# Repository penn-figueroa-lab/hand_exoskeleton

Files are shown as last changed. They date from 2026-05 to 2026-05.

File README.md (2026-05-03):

# Hand Exoskeleton — Figueroa Robotics Lab, University of Pennsylvania

<p align="center">
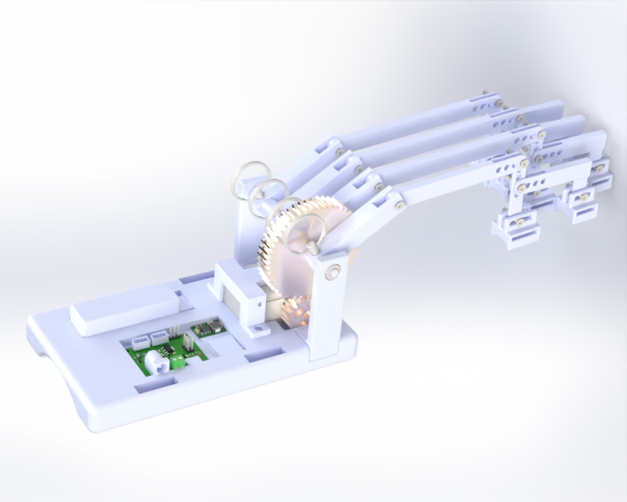
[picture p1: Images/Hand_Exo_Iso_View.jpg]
Hand Exoskeleton Rendered CAD
  
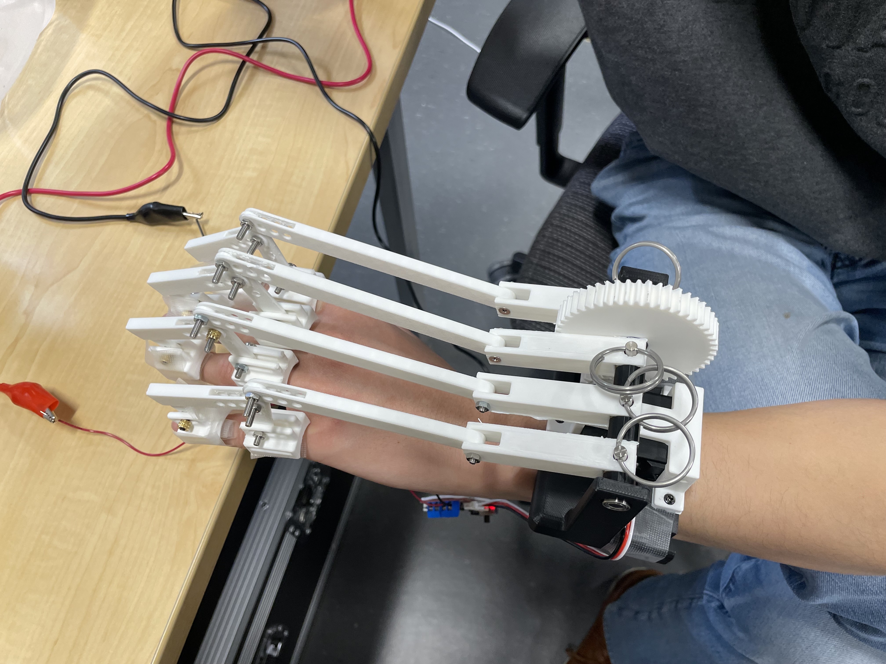
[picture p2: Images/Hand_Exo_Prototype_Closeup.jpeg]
Hand Exoskeleton Physical Prototype
  
</p>
<p align="center">
  <em>Left: SolidWorks render of the left-hand exoskeleton. Right: Physical prototype worn on a user's hand, showing the 4-finger linkage system, spur gear transmission, and wrist-mounted electronics housing.</em>
</p>

> **Status: Active Development** — Current version supports 4-finger actuation (index, middle, ring, pinky). Thumb integration is ongoing.

---

## Overview

This repository contains all design files, electronics documentation, and assembly instructions for the **Penn GRASP Lab Hand Exoskeleton** — a compact, single-motor, bidirectional hand exoskeleton designed to assist patients who retain partial voluntary hand control (e.g., post-stroke or spinal cord injury patients).

The device targets grip assistance by actuating all four fingers simultaneously through a single Waveshare ST3215 servo motor, a gear transmission, and a parallel four-bar linkage system per finger. All structural components are 3D printed in PLA on a single print bed, keeping cost and fabrication time low while maintaining sufficient mechanical strength for the target torque requirements.

This design draws inspiration from and extends the work of [Esposito et al. (2022) — *Machines*, MDPI](https://www.mdpi.com/2075-1702/10/1/57), adapting it for a more compact, wrist-mounted form factor with a spur gear transmission replacing a Bowden cable mechanism.

---

## Repository Structure

```
hand_exoskeleton/
├── Images/                        # Photos and renders used in this README
├── CAD/
│   ├── Hand Exoskeleton - Left/   # SolidWorks assembly and part files (left hand)
│   └── STL Files/                 # Exported STL files for all printed parts
├── Print files/
│   ├── BambuStudio/               # `Hand Exo.3mf` — configured for Bambu Lab P1S
│   └── Print Orientation Guide/   # PRINT_ORIENTATION_GUIDE.md + screenshots
├── Datasheets/                    # Datasheets for all electronic components
├── Code/                          # Control code for the hand exoskeleton
└── README.md
```

---

## Table of Contents

1. [Design Overview](#1-design-overview)
2. [Mechanical Design](#2-mechanical-design)
   - [Wrist Mount & Housing](#21-wrist-mount--housing)
   - [Actuation & Gear Transmission](#22-actuation--gear-transmission)
   - [Transmission Shaft & Bearings](#23-transmission-shaft--bearings)
   - [Finger Linkage System](#24-finger-linkage-system)
   - [Finger Connectors](#25-finger-connectors)
   - [Left vs. Right Hand Variants](#26-left-vs-right-hand-variants)
3. [Electronics](#3-electronics)
4. [Bill of Materials](#4-bill-of-materials)
5. [Print & Assembly Guide](#5-print--assembly-guide)
   - [Print Guide](#51-print-guide)
   - [Assembly Procedure](#52-assembly-procedure)
6. [Current Status & Future Work](#6-current-status--future-work)
7. [References](#7-references)

---

## 1. Design Overview

The exoskeleton is designed around the following core goals:

- **Single-motor, 4-finger actuation**: One ST3215 servo drives all four fingers via a shared transmission shaft, keeping the device compact and lightweight.
- **Bidirectional motion**: The motor drives both flexion (closing) and extension (opening) of the fingers.
- **Patient-targeted**: Designed for users who retain partial hand control. The device augments, rather than fully replaces, voluntary effort.
- **Adjustable fit**: Multiple mounting hole positions on each linkage and slot-based connections on finger connectors accommodate a range of finger lengths and hand sizes.
- **Fully 3D-printed structure**: All custom parts are printed in PLA using a single Bambu Lab P1S print bed (~11.5 hours, ~233g filament).

**Grip strength target**: Based on published grip strength data (male average 45 kg, female average 32 kg), the device targets 20 kg (200 N) of assistive grip force. With a 50 mm effective lever arm at the PIP joint, this requires approximately 10 Nm at the output — met by the ST3215's 30 kg·cm (2.94 Nm) stall torque multiplied through the 2.5:1 gear train and the mechanical advantage of the linkage system.

---

## 2. Mechanical Design

### 2.1 Wrist Mount & Housing

The **wrist mount** is the central structural element of the device. It:

- Houses all electronics in a dedicated bay (175 mm × 100 mm × 20 mm, L × W × H)
- Integrates the **left transmission mount** directly into its body
- Provides the motor mounting interface
- Is secured to the user's wrist via **Velcro straps** through dedicated strap channels
- Has a **curved underside** matching the natural curvature of the human wrist for comfort

The wrist mount is printed at **15% infill** except where noted. The electronics bay is open-top for accessibility.

---

### 2.2 Actuation & Gear Transmission

<p align="center">
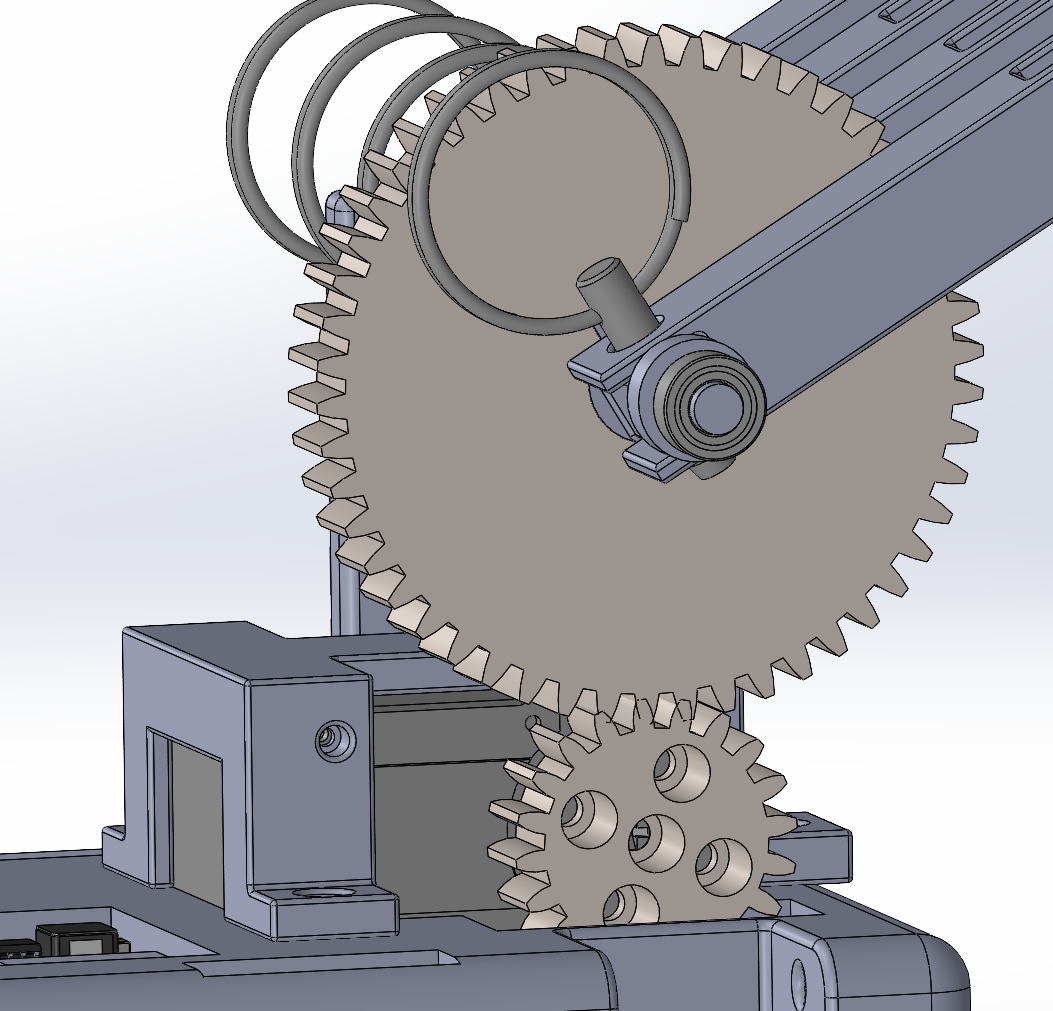
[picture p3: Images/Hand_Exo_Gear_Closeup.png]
Gear transmission closeup
  
</p>

Actuation uses a **Waveshare ST3215 serial bus servo** in position control mode, selected for its:
- High torque output: **30 kg·cm (2.94 Nm) @ 12V**
- Compact form factor: 45.22 mm × 35 mm × 24.72 mm, **69 g**
- 360° magnetic encoder with 4096-count resolution
- Two-way feedback (position, load, speed, voltage)
- Wide voltage input: 6–12.6V (compatible with 2S or 3S LiPo)
- Serial bus daisy-chain capable (up to 253 servos)

The motor is held in place by a dedicated **motor mount** that is screwed into the wrist mount.

**Gear train** (spur gear pair):

| Parameter | Small Gear (Drive) | Large Gear (Driven) |
|---|---|---|
| Module | 1.25 | 1.25 |
| Tooth Count | 20T | 50T |
| Gear Ratio | — | **2.5:1** |
| Thickness | 10 mm | 10 mm |
| Tooth Depth Modification | +0.5 mm deeper | +0.5 mm deeper |
| Infill | 75% PLA | 75% PLA |
| Mounting | Screwed to motor horn | Keywayed to transmission shaft |

> **Note on tooth depth modification**: Gear teeth are 0.5 mm deeper than the standard SolidWorks Toolbox profile to compensate for dimensional variation in 3D-printed gears and for any motor mount/transmission mount positional offsets. This ensures proper meshing and prevents slip under load.

The small gear is **directly screwed onto the ST3215 motor horn** using the horn's native mounting holes (M2.5 screws). The large gear is **press-fitted** between two fingers on the transmission shaft and secured by a keyway, ensuring full-thickness (10 mm) face-to-face mesh alignment. The motor mount position is adjusted to guarantee proper gear center distance.

---

### 2.3 Transmission Shaft & Bearings

The **transmission shaft** is the main rotating element that distributes torque from the large spur gear to all four finger base linkages.

- Printed at **75% infill** for torsional rigidity
- Mounted at both ends in **stainless steel ball bearings** for smooth, concentric rotation

**Bearing specification:**
- Type: Stainless steel, sealed
- ID: **5 mm** | OD: **10 mm** | Width: **4 mm**
- Sourced from McMaster-Carr

The **left transmission mount** is integrated into the wrist mount body. The **right transmission mount** is a separate printed part that is assembled after the shaft and large gear are in place, and is secured to the wrist mount from both the **bottom** and the **side** with screws. This split-mount design allows the shaft to be slid in laterally during assembly.

---

### 2.4 Finger Linkage System

Each finger uses a **parallel 4-bar linkage** system. This topology, established in the reference MDPI design, converts the rotational motion of the transmission shaft into a guided flexion/extension motion that closely follows the natural kinematics of the human finger.

Four base linkages are mounted to the transmission shaft, spaced **22.5 mm apart** (approximating natural inter-finger spacing). They are connected using **18-8 stainless steel quick-release pins** (McMaster-Carr), which allow any individual finger assembly to be removed instantly without tools by simply pulling the pin — far faster than unscrewing a fixed connection.

**Linkage chain per finger** (proximal to distal):

```
Transmission shaft
      │
  Base Linkage (65.4 mm)     ← Quick-release pin to shaft
      │
  Intermediate Linkage        ← M3 screw connection
  (100 mm — pinky | 130 mm — other fingers, max length)
      │
  Vertical Linkage (50 mm)   ← Multiple hole positions for adjustability
      │                         Both at top (to intermediate) and bottom (to connectors)
  ├── Base Finger Connector (MCP)   ← Slot connection for fine adjustment
  └── L-Shape Linkage (60 mm W × 28 mm L)  ← Middle holes of vertical linkage
           │
      Small Finger Connector (PIP/DIP)  ← Slot connection
```

**Key design decisions:**
- **Multiple hole positions** on the intermediate linkage end and vertical linkage allow adjustment to the user's finger length.
- **Slot connections** (rather than fixed holes) at the finger connector interfaces provide continuous adjustability for even finer fit customization.
- **PIP and DIP treated as one joint**: Rather than separate connectors for each phalanx, only two connectors are used — one at MCP and one spanning PIP/DIP — simplifying the design while maintaining functional grip guidance.
- The pinky finger uses a **shorter intermediate linkage (100 mm)** to match the shorter length of the fifth finger; all other fingers use 130 mm.

All linkage connections use **M3 screws and nuts** throughout except where quick-release pins are specified.

---

### 2.5 Finger Connectors

Two connector types are used per finger:

**Base Finger Connector (MCP)** — Large connector that attaches above the knuckle (metacarpophalangeal joint):
- Velcro-taped to the dorsal surface of the finger just proximal to the knuckle
- **Curved bottom surface** matching the natural convexity of a human finger
- Slot interface to the vertical linkage

**Small Finger Connector (PIP/DIP)** — Smaller connector that spans the proximal and distal interphalangeal joints:
- Attached to the dorsal proximal phalanx / middle phalanx region
- Also **curved** to conform to finger geometry
- Slot interface to the L-shape linkage

---

### 2.6 Left vs. Right Hand Variants

The device is designed as a left hand model. A right hand version is a simple mirror of the design — the only structural difference is the **position of the pinky (short) linkage**:

| Variant | Pinky linkage position |
|---|---|
| Left hand (current model) | Leftmost position |
| Right hand (future work) | Rightmost position |

The right hand CAD files will be added in a future update once the left hand design is fully validated and finalized.

---

## 3. Electronics

The electronics are housed in the wrist mount bay and consist of the following system:

<p align="center">
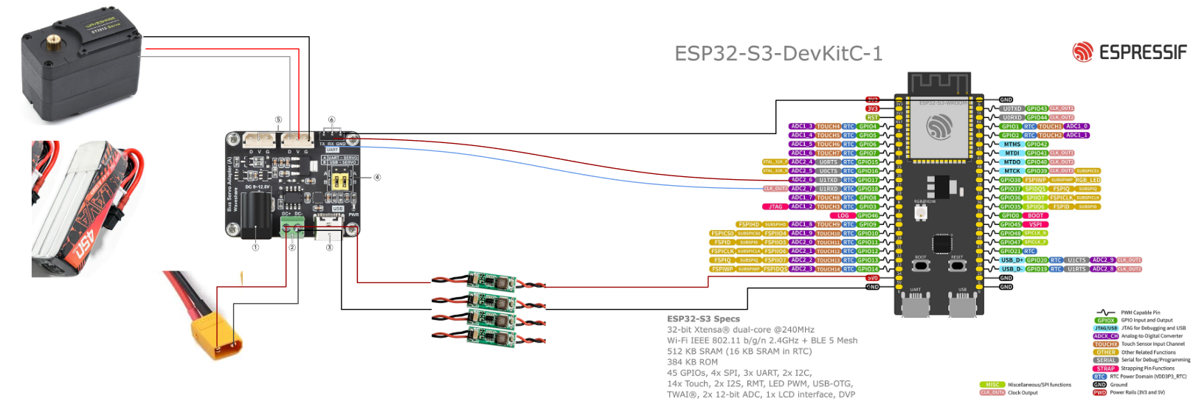
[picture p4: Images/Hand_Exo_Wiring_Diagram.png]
Wiring diagram
  
</p>

### Power Architecture

```
3S LiPo Battery (12V, 400–600 mAh, XT30)
          │
          ├──▶ Waveshare Bus Servo Adapter A (12V direct) ──▶ ST3215 Servo
          │
          └──▶ Voltage Step-Down (12V → 5V) ──▶ ESP32-S3 (Adafruit Feather)
```

### Component List

| Component | Description | Link |
|---|---|---|
| **Waveshare ST3215 Servo** | 30 kg·cm @ 12V, 360° encoder, serial bus | [Waveshare](https://www.waveshare.com/st3215-servo.htm) |
| **Waveshare Bus Servo Adapter A** | Serial bus interface, 12V servo power supply | [Waveshare](https://www.waveshare.com/bus-servo-adapter-a.htm) |
| **ESP32-S3 (Adafruit Feather S3)** | Microcontroller, 5V, Wi-Fi + BLE, UART servo control | [Adafruit #5364](https://www.adafruit.com/product/5364) |
| **Step-Down Converter (Mini360)** | 12V → 5V buck converter for ESP32 | [Amazon](https://www.amazon.com/ALMOCN-Mini360-Voltage-Converter-4-75V-23V/dp/B08HQDSQZP) |
| **3S LiPo Battery** | 12V, 400–600 mAh, XT30 connector, ~38g | [Pyrodrone](https://pyrodrone.com/collections/3s-batteries/products/betafpv-lava-3s-450mah-75c-xt30-battery-2pcs) |
| **XT30 Pigtail** | Battery connector pigtail | [Amazon](https://www.amazon.com/xt30-pigtail/s?k=xt30+pigtail) |
| **Waveshare Bus Servo Driver Hat A** | Alternative Raspberry Pi–compatible driver hat | [Waveshare](https://www.waveshare.com/bus-servo-driver-hat-a.htm) |

> **Future development**: A custom PCB integrating the step-down converter, ESP32, and bus servo adapter into a single wrist-mount-sized board is planned for a later hardware revision.

### Wiring Notes

- The ST3215 communicates over **half-duplex UART** (TTL serial) at up to 1 Mbps. The Bus Servo Adapter A handles the TX/RX level-shifting and provides 12V motor power.
- The ESP32-S3 is powered from the 5V step-down output and communicates with the servo adapter via UART.
- A **decoupling capacitor** should be added between V+ and GND on the servo power rail in the final circuit to suppress voltage spikes during motor commutation.
- All electronics are seated on standoffs inside the wrist mount bay and can be accessed by removing the wrist mount cover.

---

## 4. Bill of Materials

### Purchased Hardware

| Item | Specification | Source | Qty | Unit Cost (USD) |
|---|---|---|---|---|
| Waveshare ST3215 Servo | 30 kg·cm @ 12V, 360° encoder, serial bus | Waveshare | 1 | ~$25 |
| Ball Bearing | SS, 5mm ID × 10mm OD × 4mm W, sealed | McMaster-Carr | 2 | ~$5 ea |
| Quick-Release Pin | 18-8 SS, sized to base linkage holes | McMaster-Carr | 4 | ~$2 ea |
| M3 Screw & Nut Set | Various lengths (6 mm, 10 mm, 16 mm) | McMaster-Carr / Amazon | ~40 | — |
| M2.5 Screw | For motor horn attachment to small spur gear | McMaster-Carr | 4 | — |
| Velcro Straps | Hook-and-loop, wrist and finger attachment | Amazon | — | ~$8 |
| Waveshare Bus Servo Adapter A | 12V bus servo power + UART interface | Waveshare | 1 | ~$15 |
| ESP32-S3 Feather (Adafruit #5364) | 5V, Wi-Fi + BLE | Adafruit | 1 | ~$25 |
| Mini360 Buck Converter | 12V → 5V step-down | Amazon | 1 | ~$2 |
| 3S LiPo Battery | 400–600 mAh, XT30, ~38g | Pyrodrone / Amazon | 1 | ~$15 |
| XT30 Pigtail | Battery connector | Amazon | 1 | ~$3 |
| Misc (wires, standoffs, heat shrink, plugs) | — | — | — | ~$10 |

### 3D-Printed Parts

All parts are printed in **PLA** unless otherwise noted.

| Part | Qty | Infill | Notes |
|---|---|---|---|
| Wrist Mount | 1 | 15% | Electronics bay + left transmission mount integrated |
| Motor Mount | 1 | 15% | — |
| Right Transmission Mount | 1 | 15% | Separate piece; slides over shaft |
| Transmission Shaft | 1 | **75%** | Torque-transmitting; keywayed |
| Large Spur Gear (50T, M1.25) | 1 | **75%** | +0.5 mm tooth depth, keywayed |
| Small Spur Gear (20T, M1.25) | 1 | **75%** | +0.5 mm tooth depth, motor horn mount |
| Base Linkage | 4 | 15% | 65.4 mm, one per finger |
| Intermediate Linkage — Standard (130 mm) | 3 | 15% | Index, middle, ring fingers |
| Intermediate Linkage — Short (100 mm) | 1 | 15% | Pinky finger |
| Vertical Linkage | 4 | 15% | 50 mm, multiple mounting holes |
| L-Shape Linkage | 4 | 15% | 60 mm W × 28 mm L |
| Base Finger Connector (MCP) | 4 | 15% | Large connector; curved underside |
| Small Finger Connector (PIP/DIP) | 4 | 15% | Smaller connector; curved underside |

> **Total estimated filament**: ~217g (model), ~233g total including support | **Print time**: ~11h25m on Bambu Lab P1S (single bed)

---

## 5. Print & Assembly Guide

### 5.1 Print Guide

See [`Print files/Print Orientation Guide/PRINT_ORIENTATION_GUIDE.md`](Print%20files/Print%20Orientation%20Guide/PRINT_ORIENTATION_GUIDE.md) for the complete print setup, bed layout screenshots, and per-part orientation guidance.

**Summary:**

| Print Bed | Parts Included | Infill | Material |
|---|---|---|---|
| Bed 1 (single plate) | All parts combined | Mixed (see BOM above) | PLA |

- Gears and transmission shaft: **75% infill**, 4 wall loops
- All other parts: **15% infill**, 4 wall loops
- All parts fit on a **single Bambu Lab P1S bed** (~256 mm × 256 mm)
- Supports are required on the wrist mount and finger connectors; remove carefully after printing

> **Tip**: View `Hand Exo.3mf` in **Line Type** color scheme in Bambu Studio to distinguish support material from part material before starting the print.

---

### 5.2 Assembly Procedure

**Before assembly, gather:**
- All 3D-printed parts (supports removed and cleaned up)
- 2× stainless steel ball bearings (5mm ID × 10mm OD × 4mm)
- 4× 18-8 SS quick-release pins
- M3 screws and nuts (various lengths)
- M2.5 screws (for motor horn)
- Velcro straps (wrist and finger)
- All electronic components

---

**Step 1 — Assemble all four finger linkage systems**

For each finger, assemble in the following order:

1. Connect the **intermediate linkage** to the base linkage via M3 screw and nut — select the appropriate hole on the intermediate linkage for the user's finger length
2. Connect the **vertical linkage** to the intermediate linkage via M3 screw and nut through the chosen hole position
3. Slide the **base finger connector (MCP)** onto the slot of the vertical linkage and secure with M3 screw and nut
4. Attach the **L-shape linkage** to the middle holes of the vertical linkage via M3 screw and nut
5. Slide the **small finger connector (PIP/DIP)** onto the slot of the L-shape linkage and secure with M3 screw and nut

Repeat for all four fingers. Use the shorter intermediate linkage (100 mm) for the pinky.

---

**Step 2 — Prepare the motor**

Screw the **small spur gear (20T)** onto the ST3215 motor horn using M2.5 screws through the horn's native mounting holes. Ensure the gear seats flush against the horn face.

---

**Step 3 — Mount the motor**

Place the **motor** into the **motor mount** and secure with screws. Then mount the motor mount assembly into the wrist mount and screw it down.

---

**Step 4 — Install the large spur gear**

Press-fit the **large spur gear (50T)** into the gap between the two transmission shaft fingers on the wrist mount, aligning the keyway. The gear should be fully seated with its full 10 mm face engaged.

---

**Step 5 — Attach finger linkages to the transmission shaft**

Slide all four finger base linkages onto the transmission shaft at 22.5 mm spacing, aligning with their respective positions. Insert the **quick-release pins** through each base linkage and transmission shaft to secure them.

---

**Step 6 — Install the transmission shaft and bearings**

1. Press one ball bearing into the **right transmission mount** bearing seat and one into the integrated bearing seat on the **left transmission mount** (built into the wrist mount)
2. Slide the **transmission shaft** through the left bearing, through the gear, and into the right bearing
3. Screw the **right transmission mount** to the wrist mount from the bottom and the side using the designated screw holes

---

**Step 7 — Verify gear mesh**

Manually rotate the motor horn to confirm smooth meshing between the small and large spur gears. There should be no binding or excessive play. If necessary, adjust the motor mount position slightly to optimize center distance.

---

**Step 8 — Install electronics**

Seat all electronics components (ESP32, Bus Servo Adapter, step-down converter, battery) into the wrist mount electronics bay on standoffs. Connect wiring per the wiring diagram in Section 3.

---

**Step 9 — Don the device**

1. Place the wrist mount on the dorsal surface of the wrist and secure with **Velcro straps**
2. Align the MCP finger connectors just proximal to each knuckle and attach with **Velcro straps**
3. Align the PIP/DIP finger connectors on the middle phalanx region and attach with **Velcro straps**
4. Confirm that all linkages move freely through the range of motion without pinching

---

**Step 10 — Power on and test**

Connect the battery and power on the device. Command the servo to flex and extend the fingers to verify full range of motion and confirm no binding in the linkage system.

---

## 6. Current Status & Future Work

| Item | Status |
|---|---|
| 4-finger mechanical design (left hand) | ✅ Complete |
| Gear transmission + transmission shaft | ✅ Complete |
| Electronics architecture | ✅ Defined |
| Physical assembly & first hardware build | ✅ Complete — see prototype photo above |
| Smooth finger actuation (linkage kinematics refinement) | 🔄 In progress — current design does not yet produce smooth motion when motor is actuated; linkage geometry and transmission tuning ongoing |
| Wrist mount housing optimization | 🔄 In progress — current wrist mount is first-pass geometry; electronics mounting, cable routing, and cover design not yet finalized |
| Right hand variant CAD | 🔲 Future work |
| Thumb integration | 🔲 Future work |
| EMG-based control | 🔲 Future work |
| Custom PCB (integrated electronics) | 🔲 Future work |
| Clinical testing / patient trials | 🔲 Future work |

---

## 7. References

- Esposito, D. et al. (2022). *A Mechanical Hand Exoskeleton for Rehabilitation of Post-Stroke and SCI Patients*. Machines, 10(1), 57. [https://www.mdpi.com/2075-1702/10/1/57](https://www.mdpi.com/2075-1702/10/1/57)
- Waveshare ST3215 Servo: [https://www.waveshare.com/st3215-servo.htm](https://www.waveshare.com/st3215-servo.htm)
- Grip strength reference data: Leyk et al. (2007), [Springer](https://link.springer.com/article/10.1186/s12891-015-0612-4/tables/2)

---

*Developed at the [Figueroa Robotics Lab](https://github.com/penn-figueroa-lab), University of Pennsylvania GRASP Laboratory.*

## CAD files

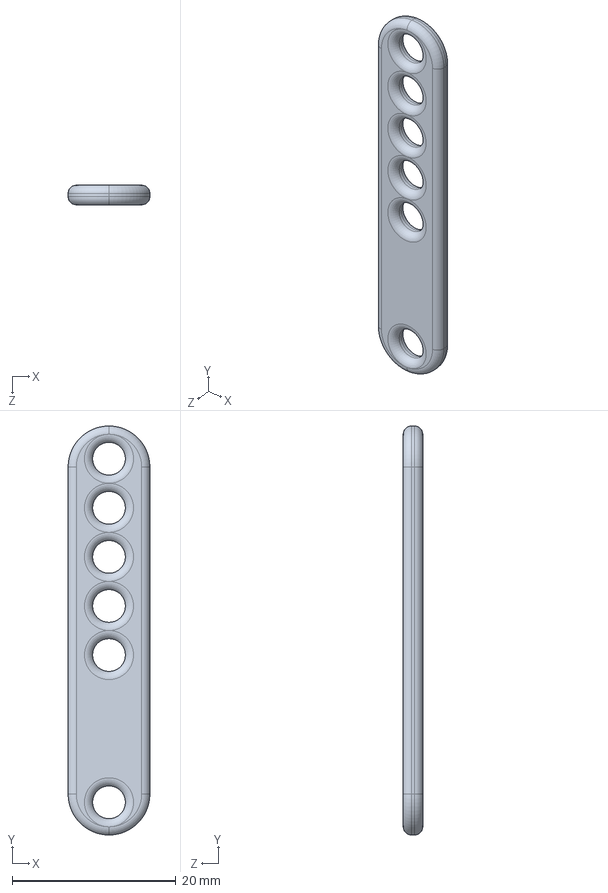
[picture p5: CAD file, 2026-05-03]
CAD/Hand Exoskeleton - Left/Vertical linkage.SLDPRT
10.0 x 50.0 x 2.40 mm

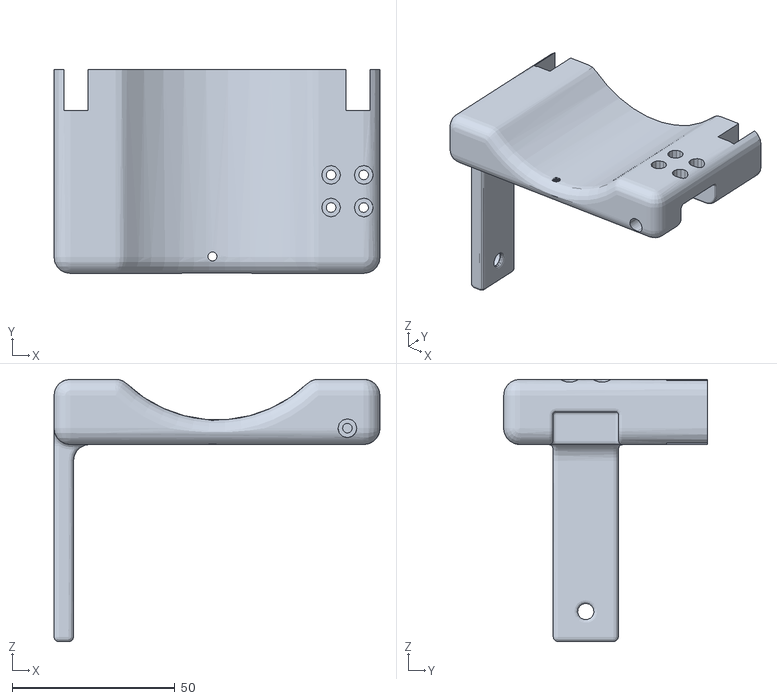
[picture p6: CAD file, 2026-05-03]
CAD/STL files/Wrist mount.STL
100.0 x 62.5 x 80.5

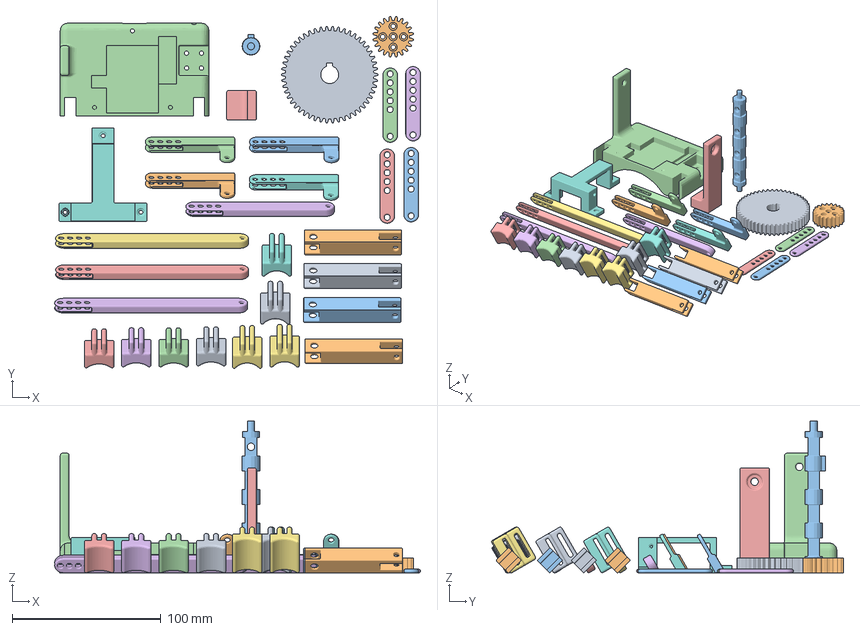
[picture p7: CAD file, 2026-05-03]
Print files/Bambu Studio/Hand Exo.3mf
246.2 x 236.8 x 102.0 mm
Big spur gear.STL
Small spur gear.STL
Transmission shaft.STL
Wrist mount.STL
Wrist stand.STL
Intermediate linkage - pinky.STL
Long finger attachment.STL x 4
Motor mount.STL
Short finger attachment.STL x 4
Transmission linkage.STL x 4
Vertical linkage.STL x 4
Intermediate linkage.STL x 3
L linkage.STL x 4

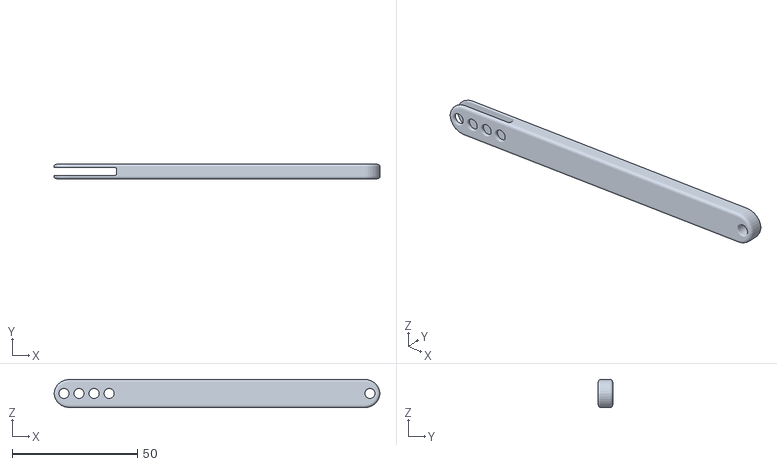
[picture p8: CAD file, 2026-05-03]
CAD/STL files/Intermediate linkage.STL
130.0 x 5.80 x 11.2

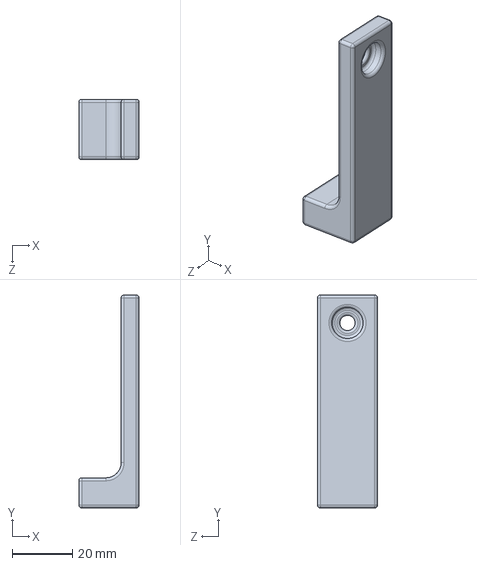
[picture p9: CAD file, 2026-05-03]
CAD/Hand Exoskeleton - Left/Wrist stand.SLDPRT
20.0 x 70.5 x 20.0 mm

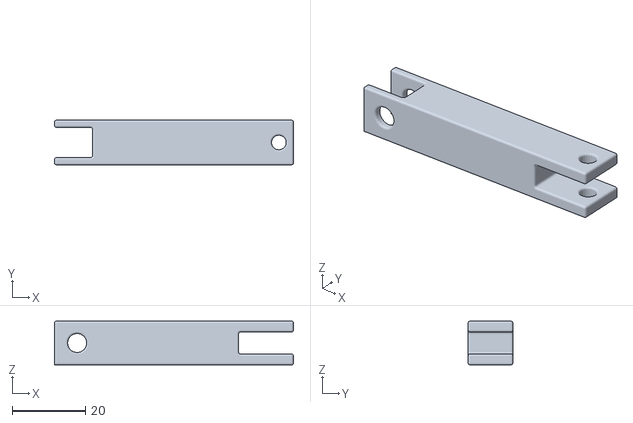
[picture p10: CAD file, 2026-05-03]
CAD/STL files/Transmission linkage.STL
65.4 x 12.2 x 12.0

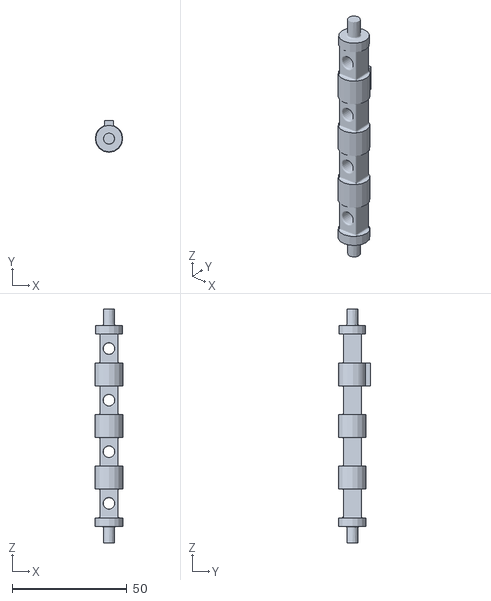
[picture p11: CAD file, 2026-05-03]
CAD/STL files/Transmission shaft.STL
12.0 x 13.8 x 102.0

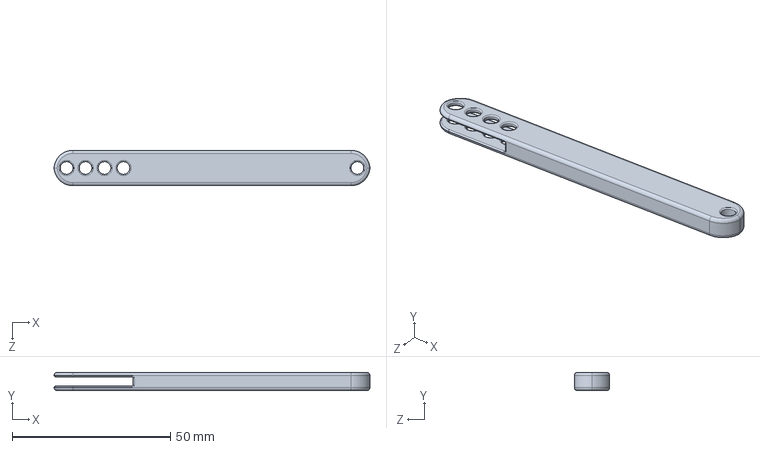
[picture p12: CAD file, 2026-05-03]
CAD/Hand Exoskeleton - Left/Intermediate linkage - pinky.SLDPRT
100.0 x 5.80 x 11.2 mm

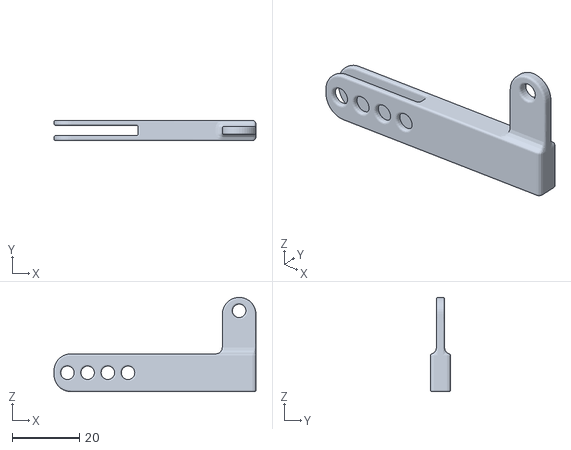
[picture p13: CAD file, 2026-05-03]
CAD/STL files/L linkage.STL
60.0 x 6.00 x 28.0

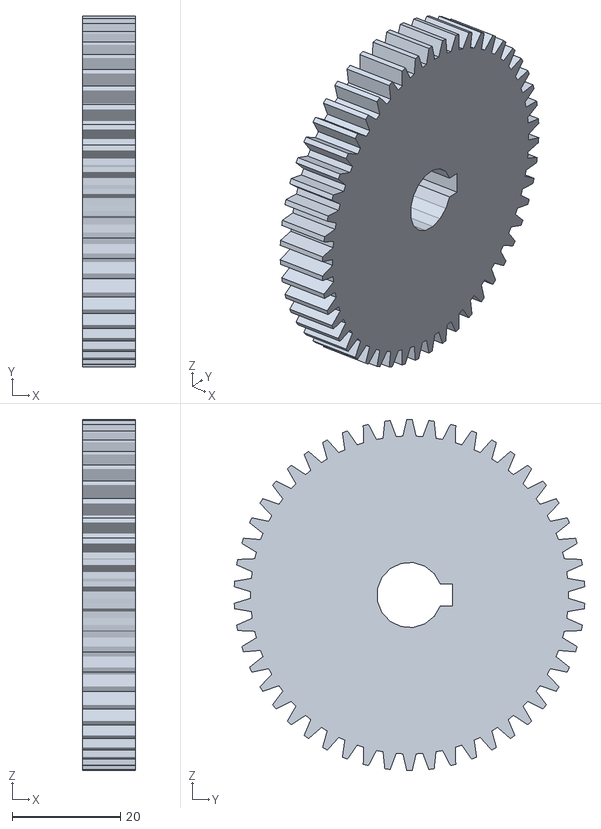
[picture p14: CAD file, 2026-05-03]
CAD/STL files/Big spur gear 0_5.STL
9.90 x 64.9 x 65.0

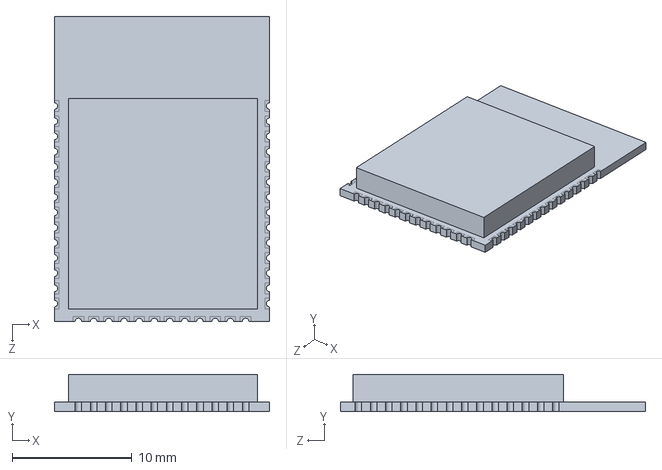
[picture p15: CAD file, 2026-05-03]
CAD/Hand Exoskeleton - Left/ESP32-S3-WROOM-2.SLDPRT
18.0 x 3.11 x 25.5 mm

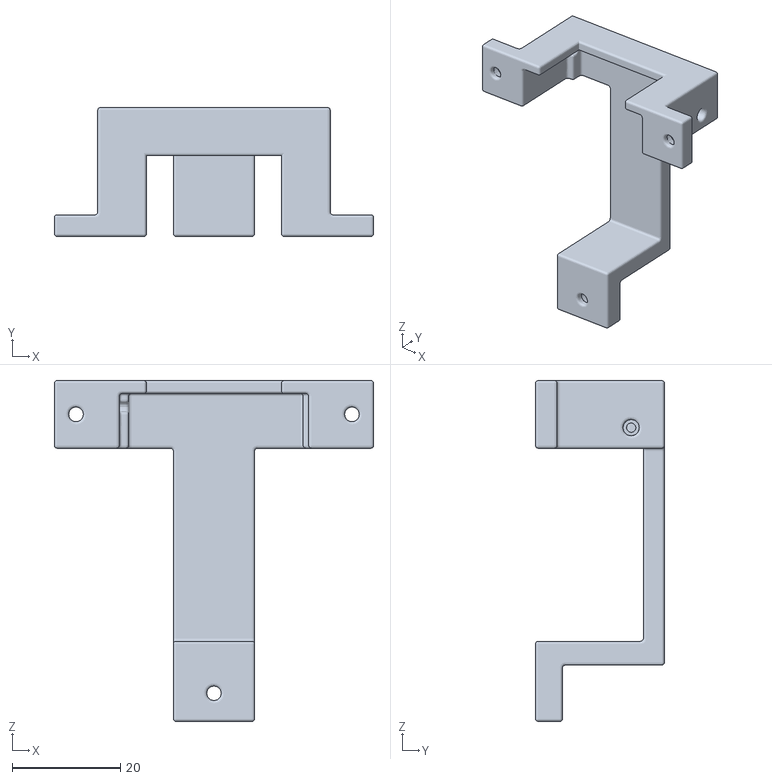
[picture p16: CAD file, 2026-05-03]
CAD/STL files/Motor mount.STL
58.9 x 23.8 x 62.9

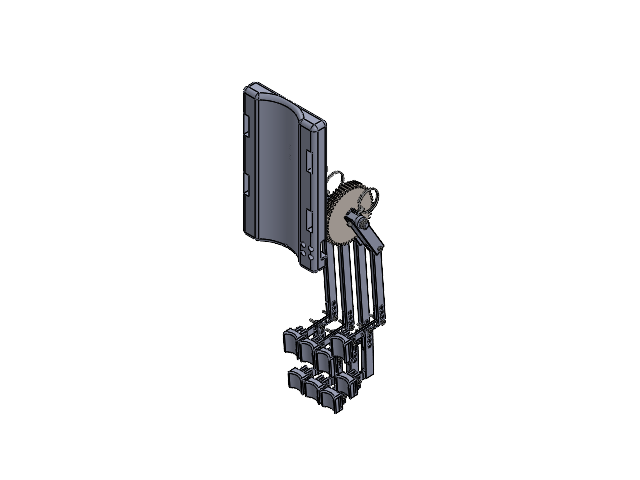
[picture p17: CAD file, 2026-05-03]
CAD/Hand Exoskeleton - Left/Hand Exo V2.1.SLDASM
Wrist mount
Transmission shaft
Transmission linkage x 4
STS3215 Servo motor
spur gear_am x 2
Servo Adapter
ESP32-S3-WROOM-2
BETAFPV LAVA 3S Battery
Mini360 Voltage Step down Converter Buck Module
Motor mount
98404A005_18-8 Stainless Steel Ring-Grip Quick-Release Pin x 4
Intermediate linkage x 3
Vertical linkage x 4
Long finger attachment x 4
Short finger attachment x 4
Intermediate linkage - pinky
L linkage x 4
92125A135_18-8 Stainless Steel Hex-Drive Flat Head Screw M3 18mm x 20
90591A250_Zinc-Plated Steel Hex Nut M3 x 20
7804K106_Stainless Steel Ball Bearing 5mm ID 10mm OD 4mm width x 2

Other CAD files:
CAD/Hand Exoskeleton - Left/Small spur gear.SLDASM
CAD/Hand Exoskeleton - Left/Big spur gear.SLDASM
CAD/Hand Exoskeleton - Left/Transmission shaft.SLDPRT
CAD/STL files/Vertical linkage.STL
CAD/Hand Exoskeleton - Left/Intermediate linkage.SLDPRT
CAD/Hand Exoskeleton - Left/7804K106_Stainless Steel Ball Bearing 5mm ID 10mm OD 4mm width.SLDPRT
CAD/Hand Exoskeleton - Left/90591A250_Zinc-Plated Steel Hex Nut M3.SLDPRT
CAD/Hand Exoskeleton - Left/90985A100_Knob-Grip Locking Quick-Release Pin.SLDPRT
CAD/Hand Exoskeleton - Left/92125A135_18-8 Stainless Steel Hex-Drive Flat Head Screw M3 18mm.SLDPRT
CAD/Hand Exoskeleton - Left/98404A005_18-8 Stainless Steel Ring-Grip Quick-Release Pin.SLDPRT
CAD/Hand Exoskeleton - Left/BETAFPV LAVA 3S Battery.SLDPRT
CAD/Hand Exoskeleton - Left/L linkage.SLDPRT
CAD/Hand Exoskeleton - Left/Long finger attachment.SLDPRT
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

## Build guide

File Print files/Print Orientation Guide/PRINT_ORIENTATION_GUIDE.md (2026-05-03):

# 🖨️ Print Guide — Hand Exoskeleton

This guide covers the print setup for all 3D-printed parts of the hand exoskeleton. The Bambu Studio `.3mf` project file (`Hand Exo.3mf`) is configured for the **Bambu Lab P1S** and is available in `Print files/BambuStudio/`. It is recommended to view the print in **Line Type** color scheme in Bambu Studio to distinguish support structures from actual part filament before printing.

---

## Print Settings Summary

| Part | Material | Infill | Wall Loops | Notes |
|---|---|---|---|---|
| Wrist Mount | PLA | 15% | 4 | Supports required |
| Motor Mount | PLA | 15% | 4 | — |
| Right Transmission Mount | PLA | 15% | 4 | — |
| Transmission Shaft | PLA | **75%** | 4 | Torque-transmitting part |
| Large Spur Gear (50T) | PLA | **75%** | 4 | Torque-transmitting part |
| Small Spur Gear (20T) | PLA | **75%** | 4 | Torque-transmitting part |
| Base Linkages (×4) | PLA | 15% | 4 | — |
| Intermediate Linkages — Standard 130mm (×3) | PLA | 15% | 4 | Index, middle, ring |
| Intermediate Linkage — Short 100mm (×1) | PLA | 15% | 4 | Pinky finger |
| Vertical Linkages (×4) | PLA | 15% | 4 | — |
| L-Shape Linkages (×4) | PLA | 15% | 4 | — |
| Base Finger Connectors / MCP (×4) | PLA | 15% | 4 | Supports required |
| Small Finger Connectors / PIP+DIP (×4) | PLA | 15% | 4 | Supports required |

> ⚠️ **Critical**: The transmission shaft and both spur gears **must** be printed at 75% infill. These parts carry torsional loads and will fail at lower infill densities.

---

## Print Bed Layout

All parts fit onto a **single Bambu Lab P1S print bed** (256 mm × 256 mm). The `Hand Exo.3mf` project file in `Print files/BambuStudio/` has all parts pre-arranged and pre-configured.

**Total print statistics (from Bambu Studio slice):**

| Parameter | Value |
|---|---|
| Total filament | ~232.53 g |
| Model filament | ~216.94 g |
| Support filament | ~15.11 g |
| Total print time | ~11 hours 25 minutes |
| Estimated cost | ~$5.81 |

<p align="center">
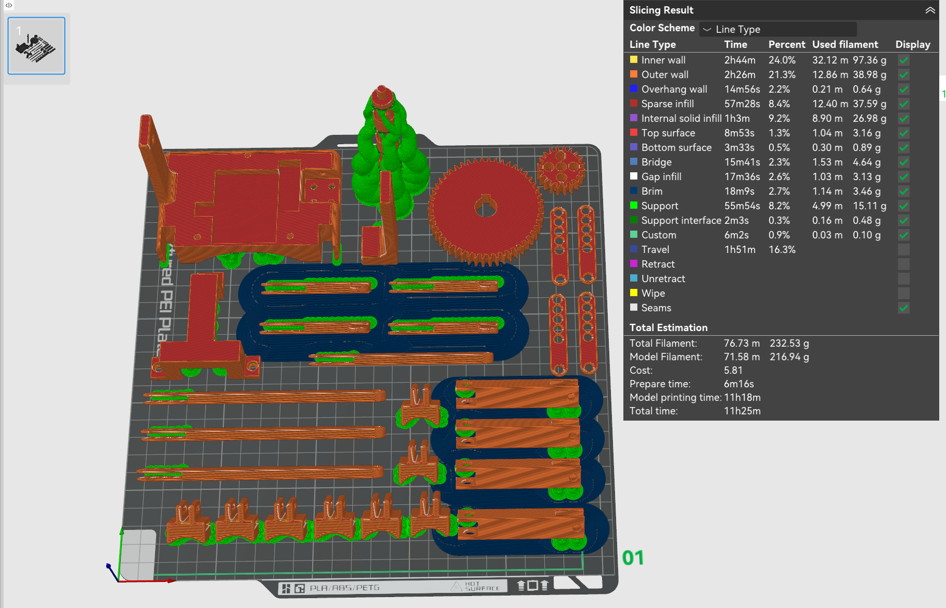
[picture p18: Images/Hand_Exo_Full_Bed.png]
Full bed slice view in Bambu Studio
  
</p>

*Full bed layout shown in Line Type color scheme. Red = part infill and walls. Green = support structures. Blue = brim.*

---

## Part Orientation Guidelines

### Transmission Shaft
Print **horizontal / flat on the bed**. This gives the best layer orientation for torsional strength along the shaft's length and the best surface finish on the shaft geometry. No supports needed.

### L-Shape Linkages, Intermediate Linkages & Finger Connectors (MCP and PIP/DIP)
Print at a **~30° tilt** to minimize the amount of support material needed on the curved and slotted faces. This significantly reduces support cleanup time while maintaining good surface quality on the contact surfaces.

---

## Support Removal Tips

- Use **flush cutters** or **needle-nose pliers** to remove support material from the inside of the finger connector slots. Do not use excessive force — the slot walls are thin.
- For the wrist mount, pay attention to removing supports from the bearing seat in the left transmission mount (integrated). Use a small screwdriver or pick to clear out any remaining support filament.
- After removing all supports, test-fit the ball bearings in both transmission mount seats before final assembly. The bearing should press in with moderate hand pressure — if it falls in freely, the seat is too large; if it doesn't seat, lightly sand or use a heat gun briefly on the plastic around the seat to relax it.

---

## Bed Adhesion

- Use a **smooth PEI plate** for best results with PLA.
- If parts are not adhering, add a **5 mm brim** to the large flat parts (wrist mount, linkages) in Bambu Studio before slicing.
- First layer height: **0.2 mm** (default for PLA in Bambu Studio).

---

[⬆ Back to Main README](../../README.md)

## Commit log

2026-05-03 Revise README for Hand Exoskeleton project
    Updated README to provide detailed project overview, structure, and assembly instructions for the Hand Exoskeleton.
2026-05-03 Add print orientation guide for hand exoskeleton
    This document provides detailed print settings, bed layout, part orientation guidelines, and support removal tips for 3D printing the hand exoskeleton components using the Bambu Lab P1S.
2026-05-03 Clarify .3mf project file name in print guide
    Updated references to the .3mf project file name for clarity.
2026-05-03 Enhance README with prototype image and assembly status
    Added a prototype photo and updated the status of the physical assembly.
2026-05-03 Fix formatting and capitalization in print guide
2026-05-03 Reorganize assembly steps and update references
2026-05-03 Update image path in PRINT_ORIENTATION_GUIDE.md
2026-05-03 Revise print statistics and section headings
    Updated total print statistics and adjusted section titles for clarity.
2026-05-03 Correct filament weight and print time in README
    Updated filament weight and print time estimates in the README.
